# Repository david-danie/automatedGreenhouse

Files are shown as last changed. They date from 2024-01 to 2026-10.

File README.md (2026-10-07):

# SmartPlant — Controlador de Cultivo IoT

<div align="justify">

SmartPlant es un sistema embebido que controla iluminación por espectro, riego y ventilación de un cultivo indoor, y se configura desde el celular mediante un portal Wi-Fi servido por el propio microcontrolador — sin app, sin nube obligatoria, sin frameworks de terceros. La principal motivación de este proyecto es generar **independencia alimentaria** respecto a las especies que se adapten a estas tecnologías, contemplando principalmente hortalizas.

</div>

<br>
<div align="center">
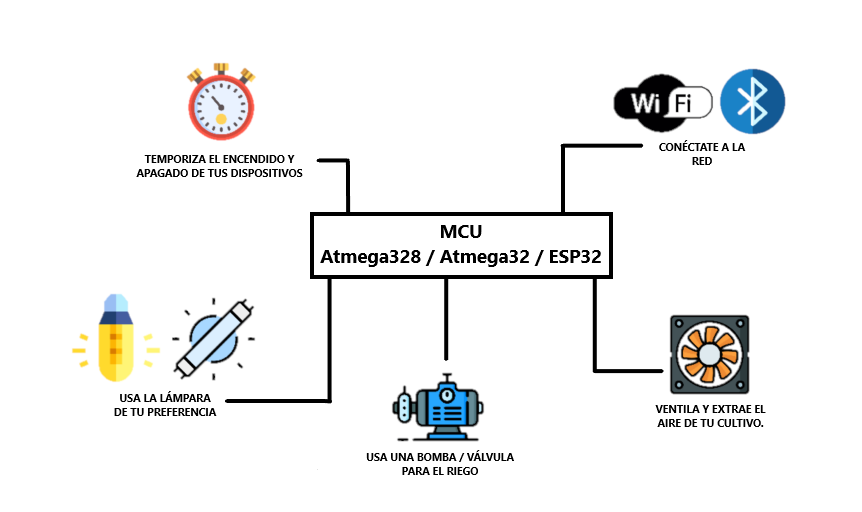
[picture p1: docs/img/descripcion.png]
Diagrama general del sistema
  
</div>
<br>

<div align="justify">

SmartPlant está construido sobre un **ESP32-C3** (RISC-V, 1 núcleo @160 MHz) con portal captivo, frontend embebido y una arquitectura pensada para escalar hacia un backend con telemetría y OTA segura.

</div>

<br>

`C++` · `ESP32-C3` · `Arduino / ESP-IDF` · `Vanilla JS` · `HTML/CSS` · `mbedTLS (planned)` · `FastAPI + PostgreSQL (in progress)`

---

## CONTENIDO

* [QUÉ DEMUESTRA ESTE PROYECTO.](#qué-demuestra-este-proyecto)
* [DECISIONES DE INGENIERÍA.](#decisiones-de-ingeniería)
* [CARACTERÍSTICAS.](#características)
* [ARQUITECTURA.](#arquitectura)
* [EL PORTAL.](#el-portal)
* [DISPOSITIVOS A CONTROLAR.](#dispositivos-a-controlar)
  - [Lámparas de cultivo.](#lámparas-de-cultivo)
  - [Bomba para irrigación.](#bomba-para-irrigación)
  - [Ventilación/Extracción.](#ventilaciónextracción)
* [TARJETA DE CONTROL.](#tarjeta-de-control)
* [STACK TECNOLÓGICO.](#stack-tecnológico)
* [ESTRUCTURA DEL REPOSITORIO.](#estructura-del-repositorio)
* [COMPILAR Y FLASHEAR.](#compilar-y-flashear)
* [ROADMAP.](#roadmap)
* [DOCUMENTACIÓN.](#documentación)

---

## QUÉ DEMUESTRA ESTE PROYECTO

<div align="justify">

Un sistema **embebido de extremo a extremo** construido bajo restricciones reales de hardware (1 núcleo RISC-V @160 MHz, RAM y flash limitadas):

- **Firmware en C++** para ESP32-C3: PWM multicanal, relés, RTC por I²C, persistencia en NVS, servidor HTTP y DNS captivo.
- **Frontend embebido**: una SPA completa (máquina de estados) en un solo HTML con vanilla JS, servida desde el flash del dispositivo — sin build, sin dependencias.
- **Diseño con trade-offs documentados**: cada decisión no trivial (scheduling, sesión, conectividad, validación) está razonada en el código y en la documentación técnica.
- **Mentalidad de producto**: UX cuidada (transiciones, estados de error, accesibilidad), seguridad por capas y un roadmap de backend/OTA pensado para el hardware.

</div>

---

## DECISIONES DE INGENIERÍA

<div align="justify">

La parte interesante de un proyecto embebido no es solo *qué* hace, sino *cómo* resuelve los problemas difíciles que impone el hardware. A continuación se documentan las decisiones más relevantes:

</div>

| Reto | Solución |
|---|---|
| **Que el riego sobreviva cortes de luz** | Scheduling **stateless**: el encendido se recalcula desde un contador continuo de horas derivado del RTC (`epochHours % intervalo`). El mismo modelo cubre riego sub-diario y espaciado de varios días, sin depender de un contador que se perdería al apagarse. |
| **Edad del cultivo correcta tras estar apagado** | `día`/`semana` se **derivan del calendario real** (ancla `cropStart` en NVS), no de un contador — el cultivo "sigue envejeciendo" aunque el equipo estuviera off, sin desgastar flash cada noche. |
| **Conectar a Wi-Fi sin congelar el portal** | Conexión STA **no bloqueante** + **polling** desde el front: el `POST` solo arranca el intento y responde al instante; el cliente confirma vía `/getparams`. Evita bloquear `handleClient()` varios segundos. |
| **No guardar una contraseña Wi-Fi que no sirve** | **Persistencia diferida**: las credenciales se escriben en NVS *solo* cuando la conexión llega a `WL_CONNECTED` — nada de bucles de reintento tras reiniciar con credenciales inválidas. |
| **Autenticación sin reenviar credenciales** | **Token de sesión** de 128 bits (`esp_random()`), TTL fijo en RAM (muere con el reboot, expiración por `millis()` a prueba de wrap-around). El AP va cifrado con WPA2-PSK. |
| **Validación idéntica en navegador y dispositivo** | Reglas replicadas bit a bit front↔firmware, contando por **carácter UTF-8** (no bytes), para que acentos y ñ no descuadren los límites entre JS y C++. |
| **Servir 50 KB de HTML sin agotar el heap** | `send_P` entrega el portal por trozos directo desde flash. Con `send()` y un `const char*` se creaba un `String` temporal del tamaño completo, y ese pico podía fallar en modo AP+STA dejando el formulario sin cargar. |
| **Menos flash y carga más rápida del portal** | El HTML legible (fuente de verdad) se regenera sin comentarios y **comprimido con gzip** al artefacto que sirve el ESP32: de ~93 KB a **~16 KB (−83 %)**. `handleRoot` lo entrega con `Content-Encoding: gzip` y el navegador lo descomprime solo. |

---

## CARACTERÍSTICAS

<div align="justify">

- **Portal captivo Wi-Fi** (AP "SmartPlant" con WPA2): se configura desde cualquier navegador, sin instalar nada.
- **Iluminación por espectro** (azul / rojo vía PWM, blanco ON/OFF), con fotoperiodo que puede cruzar medianoche.
- **Riego y ventilación** programables por intervalo (de cada hora a semanal).
- **RTC externo DS3231**: la hora se sincroniza desde el navegador del usuario.
- **Conectividad Wi-Fi del usuario** (modo AP+STA condicional) para habilitar nube/telemetría a futuro.
- **Sesión con token** + reset de fábrica protegido.
- **Aplicación de parámetros en vivo** (sin reiniciar el dispositivo).

</div>

---

## ARQUITECTURA

```
┌──────────────┐   Wi-Fi (WPA2)   ┌─────────────────────────────┐
│  📱 Cliente   │ ────────────────▶│   ESP32-C3  "SmartPlant"    │
│ (navegador)  │   HTTP / JSON    │ ┌─────────────────────────┐ │
└──────────────┘                  │ │ Portal captivo (AP)     │ │
                                  │ │ SPA en 1 HTML (vanilla) │ │
                                  │ └─────────────────────────┘ │
   red del usuario   ◀────────────│ ┌─────────────────────────┐ │
   (Internet, futuro)             │ │ STA  (AP+STA condicional)│ │
                                  │ └─────────────────────────┘ │
                                  │  PWM LEDs · Bomba · Fan ·   │
                                  │  RTC DS3231 · NVS · Token   │
                                  └─────────────────────────────┘
```

<div align="justify">

El frontend es una **máquina de estados** (`welcome · register · view · auth · edit · wifi`) contenida en un único archivo HTML; el firmware expone una API JSON y aplica la configuración al instante. Toda la comunicación entre el navegador y el microcontrolador ocurre dentro de la red local del AP — no se requiere internet para operar.

El detalle de cada decisión está en [`docs/ARCHITECTURE.md`](docs/ARCHITECTURE.md); el contrato completo de la API en [`docs/API.md`](docs/API.md).

</div>

---

## EL PORTAL

<div align="justify">

Al conectarse a la red **SmartPlant**, el sistema operativo detecta el portal captivo y abre el formulario automáticamente. Todo el frontend es un único archivo HTML con JavaScript vanilla servido desde el flash del microcontrolador: sin build, sin CDN, sin dependencias.

</div>

<br>
<table align="center">
  <tr>
    <th>Dashboard.</th>
    <th>Edición de parámetros.</th>
    <th>Configuración de red.</th>
  </tr>
  <tr>
    <td>Dashboard del portal</td>
    <td>Edición de parámetros</td>
    <td>Configuración de red Wi-Fi</td>
  </tr>
</table>
<br>

<div align="justify">

El dashboard muestra el estado del cultivo en modo lectura; para editar hay que autenticarse, lo que emite un token de sesión válido 30 minutos. La vista de red escanea las señales disponibles y permite conectar el dispositivo a la Wi-Fi del usuario sin perder el acceso al portal.

</div>

---

## DISPOSITIVOS A CONTROLAR

<div align="justify">

Los invernaderos ofrecen muchas ventajas sobre los métodos de agricultura tradicionales. El cultivo de algunas plantas y hortalizas puede adaptarse a espacios dedicados en la ciudad. La tecnología usada en la agricultura protegida también se puede adaptar a estos lugares y puede contemplar la automatización de tareas como el riego, la ventilación y/o extracción de aire, control de fotoperiodo y también la medición de parámetros como temperatura, humedad, pH, etc.

</div>

#### LÁMPARAS DE CULTIVO.

<div align="justify">

El sol como fuente de energía es muy potente e influye directamente en el desarrollo de vida. Dentro del espectro de radiación solar encontramos la radiación fotosintéticamente activa (PAR), donde los tonos azules y rojos son los más influyentes en el desarrollo de las plantas. La tecnología LED en la actualidad ofrece alternativas para suministro de luz en los cultivos. En la implementación actual se dispone de **2 canales PWM** (azul, rojo) que permiten controlar la intensidad de cada espectro de forma granular (0–100 %), más un **canal digital ON/OFF** para el blanco, con un fotoperiodo configurable que admite cruce de medianoche.

</div>

<br>
<table align="center">
  <tr>
    <th>LEDs rojos y azules.</th>
    <th>LEDs blancos.</th>
    <th>Otras lámparas.</th>
  </tr>
</table>
<div align="center">
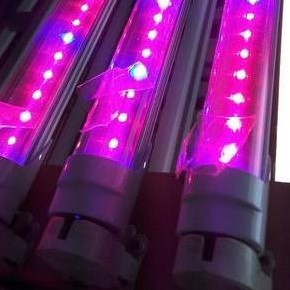
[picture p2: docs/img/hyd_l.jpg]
LEDs rojos y azules
  &emsp;&emsp;&emsp;&emsp;
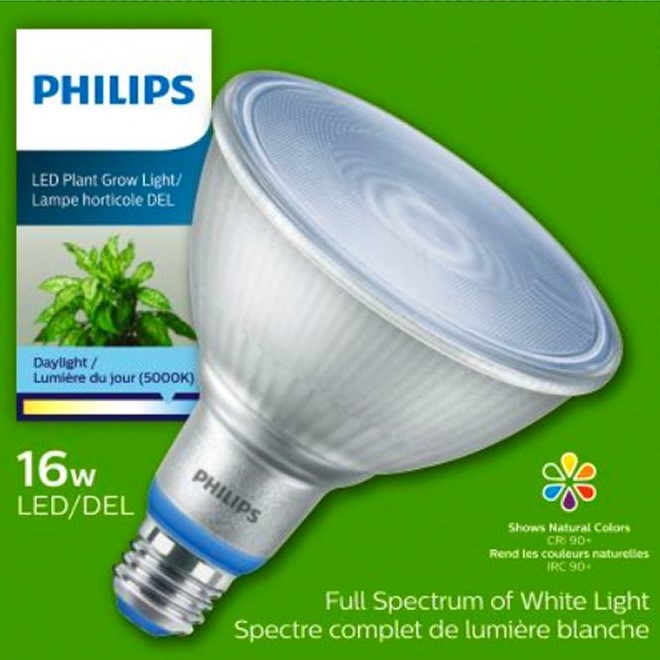
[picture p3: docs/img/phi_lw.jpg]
LEDs blancos
  &emsp;&emsp;&emsp;&emsp;
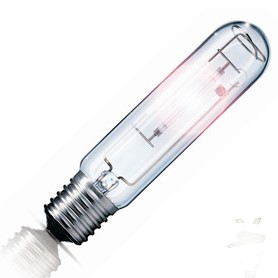
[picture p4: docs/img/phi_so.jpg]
Otras lámparas
  
</div>
<br>

#### BOMBA PARA IRRIGACIÓN.

<div align="justify">

Hay diferentes métodos de riego en la agricultura: riego por aspersión, por goteo, por gravedad, película de nutrientes, entre otros. Se hace la generalización de controlar el encendido/apagado de una bomba de agua o una electroválvula para realizar esta tarea. El sistema actual implementa un **scheduling stateless** que recalcula los ciclos de riego directamente desde el RTC, de modo que el riego se ejecuta correctamente incluso después de un corte de energía sin necesidad de persistir contadores.

</div>

<br>
<table align="center">
  <tr>
    <th>&emsp;Goteo.&emsp;</th>
    <th>&emsp;Gravedad.&emsp;</th>
    <th>&emsp;Método NFT.&emsp;</th>
    <th>&emsp;Válvula E.&emsp;</th>
  </tr>
</table>
<div align="center">
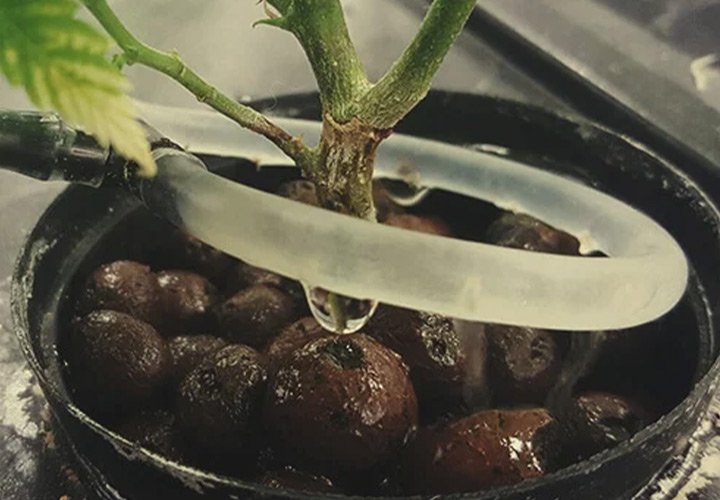
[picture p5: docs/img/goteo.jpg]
Riego por goteo
  &emsp;&emsp;&emsp;&emsp;
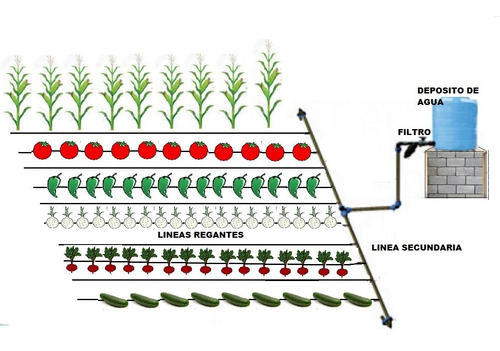
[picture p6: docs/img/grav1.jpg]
Riego por gravedad
  &emsp;&emsp;&emsp;&emsp;
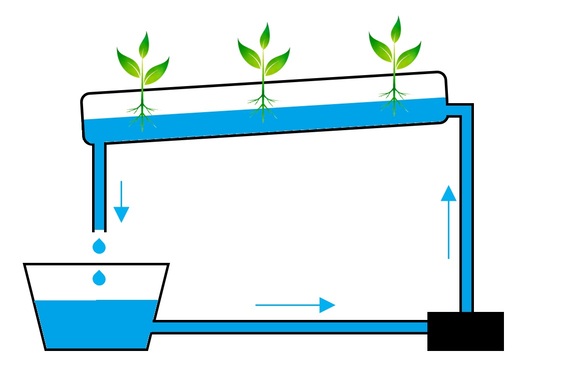
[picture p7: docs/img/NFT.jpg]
Método NFT
  &emsp;&emsp;&emsp;&emsp;
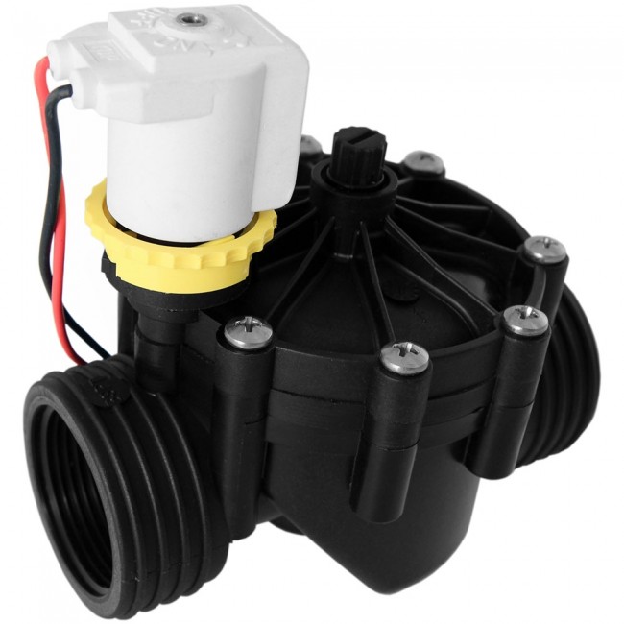
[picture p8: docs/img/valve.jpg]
Electroválvula
  
</div>
<br>

#### VENTILACIÓN/EXTRACCIÓN.

<div align="justify">

La calidad del aire de los espacios de cultivo influye en la temperatura y por lo tanto en el desarrollo de las plantas. Si es necesario forzar la circulación de aire limpio en los invernaderos y eliminar el aire viciado, se incluyen equipos de extracción y ventilación. El sistema controla un relé (lógica directa) para activar el ventilador/extractor en intervalos configurables desde el portal.

</div>

---

## TARJETA DE CONTROL

<div align="justify">

El controlador es un **ESP32-C3** (RISC-V, 1 núcleo @160 MHz) que integra Wi-Fi nativo y sirve el portal web completo directamente desde el microcontrolador.

</div>

| Componente | GPIO | Notas |
|---|---|---|
| LED blanco | 0 | Salida digital (lógica directa) |
| LED azul | 1 | PWM canal 1 |
| LED rojo | 2 | PWM canal 2 |
| Buzzer | 3 | Señalización sonora |
| Ventilador | 7 | Relé (lógica directa) |
| Bomba de agua | 10 | Relé (lógica directa) |
| RTC DS3231 | I²C `0x68` | Reloj externo para scheduling |

<div align="justify">

PWM configurado a 1 kHz con resolución de 8 bits (0–255). Los valores de espectro se envían desde el portal como porcentaje (0–100 %) y se escalan internamente en el firmware.

El detalle completo —esquemáticos, salidas SSR, RTC e instalación eléctrica— está en **[`docs/HARDWARE.md`](docs/HARDWARE.md)**.

</div>

---

## STACK TECNOLÓGICO

<div align="justify">

- **MCU:** ESP32-C3 (RISC-V, 1 núcleo @160 MHz)
- **Firmware:** C++ (Arduino-ESP32 / ESP-IDF) — `WiFi`, `WebServer`, `DNSServer`, `Wire`, `Preferences`, `ArduinoJson` (v6)
- **Frontend:** HTML + CSS + JavaScript vanilla (sin frameworks, sin build)
- **Persistencia local:** NVS (Preferences)
- **Backend (diseño cerrado, corriendo con auth y provisión):** Python (FastAPI), PostgreSQL + TimescaleDB, MQTT, almacenamiento S3-compatible. La infraestructura levanta en Docker, Alembic crea todo el esquema, el registro/login de usuarios funciona y los dispositivos ya se vinculan a una cuenta con su propio token; lo que sigue es recibir configuración y telemetría.
- **Planeado:** TLS (mbedTLS) y OTA firmada

</div>

---

## ESTRUCTURA DEL REPOSITORIO

```
.
├── ESP32_controller/          # Firmware (sketch de Arduino)
│   ├── ESP32_controller.ino   # AP Wi-Fi, DNS captivo, rutas HTTP y handlers
│   ├── Plant.h / .cpp         # Lógica del cultivo: validación, PWM/relés, RTC, sesión, Wi-Fi
│   ├── Constants.h            # Pines, PWM, límites de validación, enums de estado/error
│   ├── utils.h / .cpp         # Helpers: validación de strings/UTF-8, BCD, fecha
│   ├── sensible.h             # Secretos del AP (no versionado)
│   └── mainForm.h             # Artefacto generado: el HTML que sirve el ESP32
├── HTML/
│   ├── mainForm.html          # Pista ESTABLE (producción): fuente del portal
│   ├── mainForm.preview.html  # Preview de la estable (generado, con mock)
│   └── portal-dev/             # Pista DESARROLLO (pruebas): mainForm.html (fuente),
│                              #   mainForm.preview.html (generado) y paletas-guardadas.css
├── scripts/                   # Generadores: gen_mainform.py (--dev), gen_preview.py, gen_preview_dev.py
├── ESP32_Board/               # Diseño de la tarjeta (KiCad)
├── pythonServer/              # Backend: FastAPI + Alembic + Docker (auth funcional)
├── docs/                      # Documentación técnica
│   ├── README.md              # Índice de la documentación
│   ├── ARCHITECTURE.md        # Diseño del firmware y del portal
│   ├── API.md                 # Referencia de la API HTTP
│   ├── HARDWARE.md            # Pines, periféricos, instalación eléctrica
│   ├── BACKEND.md             # Diseño del backend
│   └── img/                   # Imágenes y diagramas
├── README.md
└── README.en.md
```

<div align="justify">

**Convención del portal — dos pistas.** El formulario se mantiene en **dos pistas** permanentes, cada una con su fuente legible y comentada:

- **Estable** (producción): `HTML/mainForm.html`
- **Desarrollo** (pruebas / features nuevas, p. ej. temperatura/humedad): `HTML/portal-dev/mainForm.html`

Se edita la fuente de cada pista y de ahí se regeneran sus artefactos, **nunca al revés**:

```bash
# Previews para revisar en el navegador sin dispositivo (cada uno inyecta su propio
# mock de fetch/XHR que simula el firmware):
python3 scripts/gen_preview.py     # -> HTML/mainForm.preview.html            (estable)
python3 scripts/gen_preview_dev.py  # -> HTML/portal-dev/mainForm.preview.html  (desarrollo)

# Promover UNA pista al artefacto embebido que sirve el ESP32 (un solo .h; se elige cuál):
python3 scripts/gen_mainform.py        # -> ESP32_controller/mainForm.h  desde la ESTABLE
python3 scripts/gen_mainform.py --dev  # -> ESP32_controller/mainForm.h  desde DESARROLLO
```

El firmware sirve **un solo** `mainForm.h`, así que promover = elegir qué pista lo
sobrescribe. Cada preview tiene su propio mock (pueden divergir a propósito: la pista de
desarrollo simula lo que va probando).

</div>

---

## COMPILAR Y FLASHEAR

```bash
# Requisitos: Arduino IDE / arduino-cli con el core ESP32 y ArduinoJson (v6).
# 1. Crear sensible.h con las credenciales del AP (ver plantilla en el código).
# 2. Compilar y flashear el sketch ESP32_controller/ a la placa ESP32-C3.
# 3. Conectarse a la red Wi-Fi "SmartPlant" → el portal captivo abre el formulario.
```

<div align="justify">

No hay test runner automatizado: la validación se hace en hardware. El JS del portal se verifica con `node --check` tras regenerar `mainForm.h` desde el HTML fuente.

</div>

---

## ROADMAP

- [x] Portal captivo + dashboard + edición de parámetros en vivo
- [x] Sesión con token (sin reenviar credenciales)
- [x] Conectividad Wi-Fi del usuario (AP+STA, escaneo asíncrono, conexión + polling)
- [x] Interruptor general del cultivo (`enable`) que realmente inhibe todos los actuadores
- [x] Modo seguro del RTC: sin hora fiable (bit OSF del DS3231) no se acciona nada
- [x] **Seguridad del portal** — los tres huecos conocidos, resueltos
      ([ver detalle](docs/ARCHITECTURE.md#huecos-de-seguridad-identificados-y-su-resolución)):
  - [x] Contraseña de usuario **hasheada** con PBKDF2-HMAC-SHA256 + salt de 16 B (queda calibrar las iteraciones en la placa)
  - [x] Reset de fábrica **restringido a la interfaz del AP**, y operación rutinaria separada en `POST /newcrop` (autenticada, conserva cuenta y Wi-Fi)
  - [x] **Límite de intentos** de login: espera creciente de 5 s a 5 min, contador en RAM
- [x] Servir el portal **gzip** (`Content-Encoding: gzip`): `gen_mainform.py` comprime el HTML y lo embebe como arreglo de bytes (`mainForm_gz`); `handleRoot` lo sirve con el encabezado. Reduce el portal de ~93 KB a ~16 KB (−83 %). Falta probarlo en hardware.
- [ ] **Portal V2** (rediseño hub-and-spoke, en desarrollo en `HTML/portal-dev/`): estructura, JS y **diseño visual completo** con **paletas intercambiables** (claras: tierra/invernadero/slate; oscura: verde-oscuro; ver `paletas-guardadas.css` y el comparador). Falta el repaso visual fino y **homologarlo** (promover con `gen_mainform.py --dev` + generar su `mainForm.h`) como versión oficial ([ver estado](docs/ARCHITECTURE.md))
- [x] **OTA local** (subir el `.bin` desde el teléfono por el AP, sin internet): endpoint `POST /otaupdate` en el firmware (librería `Update`), `partitions.csv` con dos slots OTA y **cliente en ambos portales** (V1 y V2, vistas `ota`/`flashing` con barra de progreso). Falta probar el flujo completo en hardware real ([ver requisitos](docs/ARCHITECTURE.md#requisito-crítico-tabla-de-particiones-con-dos-slots-ota))
- [ ] **Backend** (FastAPI + Postgres/Timescale): cuentas, telemetría y consulta entre dispositivos. Ya está en pie la base — la infraestructura corre en Docker (Postgres/Timescale, MinIO y Mosquitto), Alembic crea el esquema completo (5 tablas + hypertable), el registro/login/refresh funciona con JWT y los dispositivos se vinculan a una cuenta recibiendo su propio token revocable. En curso: recibir configuración y telemetría por REST (escrito, pendiente de probar). Falta exponer las lecturas para la app, servir OTA y la ingesta por MQTT ([ver estado](pythonServer/README.md))
- [ ] **OTA segura** sobre TLS (CA pinning + firmware firmado)
- [ ] Medición de temperatura y humedad (DS18B20 contemplado en el diseño original)
- [ ] **Migración del firmware a ESP-IDF**: profesionalizar el firmware (tooling, control de RAM/flash, OTA de doble slot y TLS) migrando de Arduino-ESP32 a ESP-IDF por fases entregables. El plan completo —motivación, clasificación del código, mapeo de APIs Arduino → ESP-IDF y criterios de verificación por fase— está en [`docs/ROADMAP.md`](docs/ROADMAP.md)

---

## DOCUMENTACIÓN

<div align="justify">

Toda la documentación técnica vive en **[`docs/`](docs/README.md)**:

- **[docs/ARCHITECTURE.md](docs/ARCHITECTURE.md)** — diseño técnico a fondo: decisiones, trade-offs, caveats, máquina de estados del portal, modelo de BD y estrategia TLS para el C3.
- **[docs/API.md](docs/API.md)** — referencia completa de la API HTTP: rutas, payloads, validaciones, catálogo de errores y ejemplos con `curl`.
- **[docs/HARDWARE.md](docs/HARDWARE.md)** — mapa de pines, PWM, RTC, SSR, conectividad e instalación eléctrica.
- **[docs/BACKEND.md](docs/BACKEND.md)** — diseño del backend (FastAPI + Postgres/Timescale + MQTT + S3): decisiones, modelo de datos y contratos de API. Es la referencia para implementarlo.
- **[docs/ROADMAP.md](docs/ROADMAP.md)** — plan de migración del firmware a ESP-IDF por fases: motivación, clasificación del código actual, mapeo de APIs Arduino → ESP-IDF y criterios de verificación.
- **[pythonServer/README.md](pythonServer/README.md)** — cómo levantar el backend local (FastAPI + Postgres/Timescale, MinIO, Mosquitto).

</div>

---

<div align="center">

**SmartPlant v1.0** · Firmware embebido + portal captivo para cultivo IoT

</div>

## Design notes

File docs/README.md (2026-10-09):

# Documentación de SmartPlant

Índice de la documentación técnica. Para la presentación general del proyecto, empieza por el [README de la raíz](../README.md).

---

## Por documento

| Documento | Contenido | Cuándo consultarlo |
|---|---|---|
| [**ARCHITECTURE.md**](ARCHITECTURE.md) | Diseño del firmware y del frontend a fondo: decisiones, trade-offs, caveats, máquina de estados del portal, modelo de BD y estrategia TLS para el C3 | Para entender *por qué* el código está escrito así |
| [**API.md**](API.md) | Referencia completa de la API HTTP **del dispositivo**: rutas, payloads, validaciones, catálogo de errores y ejemplos con `curl` | Para integrar algo contra el dispositivo |
| [**API-backend.md**](API-backend.md) | Referencia de la API HTTP **del backend** (nube): auth, provisión, config/telemetría del dispositivo y lecturas de la app; qué está implementado y qué no | Para integrar la app o el dispositivo contra la nube |
| [**HARDWARE.md**](HARDWARE.md) | Mapa de pines, PWM, RTC, etapa de potencia (control ↔ potencia), conectividad e instalación eléctrica | Para montar o modificar el hardware |
| [**BACKEND.md**](BACKEND.md) | Diseño del backend y **referencia autoritativa** para implementarlo: stack, modelo de datos, contratos de API, despliegue | Para retomar el desarrollo del backend |
| [**ROADMAP.md**](ROADMAP.md) | Plan de migración del firmware de Arduino-ESP32 a ESP-IDF, por fases entregables: motivación, clasificación del código, mapeo de APIs y criterios de verificación | Para planear o retomar la migración a ESP-IDF |

## Por tarea

**Quiero flashear el dispositivo y usarlo** → [README § Compilar y flashear](../README.md#compilar-y-flashear), luego [HARDWARE.md](HARDWARE.md) para el conexionado.

**Quiero modificar el portal web** → [ARCHITECTURE.md](ARCHITECTURE.md) explica la máquina de estados y la convención de regenerar `mainForm.h` desde `HTML/mainForm.html`.

**Quiero agregar o cambiar una ruta HTTP** → [API.md](API.md) es el contrato; mantenlo sincronizado con `ESP32_controller.ino` y `Plant.cpp`.

**Quiero integrar la app o el dispositivo contra la nube** → [API-backend.md](API-backend.md) es la referencia de la API del backend (lo implementado y lo pendiente); mantenla sincronizada con `pythonServer/app/routers/`.

**Quiero trabajar en el backend** → [BACKEND.md](BACKEND.md) es el diseño a implementar (referencia única); [pythonServer/README.md](../pythonServer/README.md) explica cómo levantar la infraestructura local.

**Quiero cambiar un pin o un periférico** → [HARDWARE.md](HARDWARE.md), y `ESP32_controller/Constants.h` es la fuente de verdad.

---

## Convenciones

**`Constants.h` es la fuente de verdad del hardware y de los límites de validación.** Pines, canales PWM, longitudes de campo y `validFrequencies` se definen ahí. La documentación los refleja; si divergen, el código gana.

**El portal tiene dos archivos y una dirección.** `HTML/mainForm.html` es la fuente legible y comentada; `ESP32_controller/mainForm.h` es el artefacto que sirve el dispositivo, generado a partir del anterior quitando comentarios y envolviéndolo en un raw string de C. **Se edita el `.html` y se regenera el `.h`**, nunca al revés.

**Las validaciones están duplicadas a propósito.** El navegador y el firmware aplican las mismas reglas (charset, longitudes, repetidos) contando por carácter UTF-8. Si cambias una, cambia la otra: `HTML/mainForm.html` y `Plant.cpp` / `utils.cpp`.

**Las imágenes viven en [`img/`](img).** Referéncialas con rutas relativas (`./img/archivo.png`) para que funcionen tanto en GitHub como en visores locales de Markdown.

---

## Estado del proyecto

| Área | Estado |
|---|---|
| Firmware ESP32-C3 | Funcional: portal captivo, scheduling, RTC con modo seguro, sesión, Wi-Fi AP+STA con escaneo asíncrono |
| Portal web embebido | Funcional: dashboard, edición en vivo, configuración de red |
| Hardware | Prototipo; PCB de la versión ESP32 en [`ESP32_Board/`](../ESP32_Board) (KiCad) |
| Seguridad del portal | Los tres huecos resueltos: contraseña con PBKDF2, reset restringido al AP y límite de intentos de login — [ARCHITECTURE.md](ARCHITECTURE.md#huecos-de-seguridad-identificados-y-su-resolución) |
| OTA local | Implementada: endpoint `POST /otaupdate` (firmware, librería `Update`) + `partitions.csv` de doble slot + cliente en **ambos portales** (V1 y V2). Falta probar el flujo completo en hardware — [ARCHITECTURE.md](ARCHITECTURE.md#otaupdate) |
| Portal gzip | Implementado: `gen_mainform.py` comprime el HTML (~93 KB → ~16 KB) y `handleRoot` lo sirve con `Content-Encoding: gzip`. Falta probar en hardware — [ARCHITECTURE.md](ARCHITECTURE.md#servir-el-html-comprimido-gzip) |
| Backend | Auth + provisión + config/telemetría + lecturas app-facing **implementados y verificados** end-to-end; faltan OTA/admin y MQTT — [BACKEND.md](BACKEND.md) / [API-backend.md](API-backend.md) |
| OTA segura | No iniciada; estrategia analizada en [ARCHITECTURE.md](ARCHITECTURE.md) |

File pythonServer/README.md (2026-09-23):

# SmartPlant — Backend

Servicio de nube para SmartPlant: cuentas de usuario, vinculación de dispositivos, telemetría y distribución de firmware OTA.

> **Estado: auth, provisión, config, telemetría y lecturas para la app operativas y verificadas.**
>
> El backend corre en Docker junto a la infraestructura. La migración de Alembic crea el
> esquema completo (5 tablas + hypertable), los endpoints de autenticación están operativos
> y `POST /devices/provision` ya vincula dispositivos y emite su token (todo verificado
> end-to-end).
>
> El ciclo dispositivo↔nube por REST está cerrado y verificado: `POST /devices/{id}/config`
> (histórico) y `POST /devices/{id}/telemetry` (`ts` server-side, refresca presencia). Y las
> **lecturas para la app** (§4.2) también: `GET /me/devices`, `GET /devices/{id}/state`
> (con edad de cultivo derivada) y `GET /devices/{id}/telemetry` (histórico agregado con
> `time_bucket`), todas con **aislamiento por cuenta** (404, no 403, si el device es de otra).
>
> **El diseño completo a seguir implementando está en [`../docs/BACKEND.md`](../docs/BACKEND.md).**

---

## Qué hay aquí

```
pythonServer/
├── Dockerfile                # Imagen del backend (Python 3.11 slim + uvicorn)
├── docker-compose.yml        # Stack completo: DB + MinIO + Mosquitto + backend
├── alembic.ini               # Configuración de Alembic
├── alembic/                  # Migraciones
│   ├── env.py                # Entorno async para migraciones
│   └── versions/
│       └── 001_initial_schema.py  # Esquema inicial (extensión + tablas + hypertable)
├── app/                      # Código de la API
│   ├── main.py               # FastAPI app + health endpoint
│   ├── settings.py           # Config por variables de entorno (12-factor)
│   ├── database.py           # Conexión async SQLAlchemy
│   ├── models.py             # Modelos ORM (users, devices, configs, telemetry, firmware)
│   ├── security.py           # Hashing bcrypt + generación de tokens (compartido)
│   ├── deps.py               # Dependencias de auth (Bearer → dispositivo; JWT → usuario)
│   └── routers/
│       ├── auth.py           # POST /auth/register, /auth/login, /auth/refresh
│       ├── devices.py        # POST /devices/provision, /{id}/config, /{id}/telemetry
│       └── me.py             # GET /me/devices, /devices/{id}/state, /devices/{id}/telemetry
├── db/schema.sql             # DDL de referencia (la fuente real es Alembic)
├── mosquitto/config/         # Configuración del broker
├── requirements.txt          # Dependencias con versiones clave pinneadas
├── .env.example              # Plantilla de variables de entorno
└── README.md
```

---

## Levantar el stack

```bash
cd pythonServer
cp .env.example .env          # Ajusta secretos para tu entorno
docker compose up -d --build  # Construye el backend y levanta todo
docker compose exec backend alembic upgrade head  # Crea el esquema
```

Deja corriendo cuatro servicios:

| Servicio | Puerto | Qué es |
|---|---|---|
| `backend` | 8000 | API FastAPI (SmartPlant) |
| `db` | 5432 | Postgres 15 + TimescaleDB 2.14.2 |
| `minio` | 9000 · 9001 | Object storage S3 (API · consola web) |
| `mosquitto` | 1883 | Broker MQTT |

Consola de MinIO en `http://localhost:9001` (usuario/contraseña por defecto: `admin` / `admin123456`).

Documentación OpenAPI automática en `http://localhost:8000/docs`.

### Endpoints disponibles

| Método | Ruta | Descripción |
|---|---|---|
| GET | `/health` | Health check |
| POST | `/auth/register` | Crear cuenta (devuelve JWT) |
| POST | `/auth/login` | Autenticar (devuelve JWT) |
| POST | `/auth/refresh` | Renovar access token |
| POST | `/devices/provision` | Vincular dispositivo a una cuenta y emitir su token |
| POST | `/devices/{id}/config` | Registrar config del cultivo (Bearer) |
| POST | `/devices/{id}/telemetry` | Registrar lectura de telemetría (Bearer) |
| GET | `/me/devices` | Listar dispositivos de la cuenta (JWT usuario) |
| GET | `/devices/{id}/state` | Última config + telemetría + edad del cultivo (JWT usuario) |
| GET | `/devices/{id}/telemetry` | Histórico agregado con `time_bucket` (JWT usuario) |

### El esquema lo administra Alembic

`schema.sql` es material de referencia. El dueño real del esquema es Alembic:

```bash
docker compose exec backend alembic upgrade head   # Aplica migraciones pendientes
docker compose exec backend alembic downgrade -1   # Revierte la última
```

La migración `001_initial_schema.py` crea la extensión TimescaleDB, las 5 tablas del modelo
de datos, la hypertable sobre `device_telemetry` y los índices recomendados.

Detalle de por qué Alembic no autogenera la extensión ni `create_hypertable()` en el
[§8 de `BACKEND.md`](../docs/BACKEND.md).

---

## Siguiente paso

**OTA (entregable 7 del §8).** `POST /admin/firmware` (JWT admin) sube el binario a MinIO y
registra el release; `GET /firmware/latest?current=…` resuelve aplicabilidad y devuelve una
URL prefirmada. Después vienen MQTT (entregable 8) y TLS/Caddy (entregable 9).

Nota de entorno: por defecto el stack usa los puertos **5432** (Postgres) y **8000**
(backend). Si en tu máquina esos puertos están ocupados por otro proyecto, crea un
`docker-compose.override.yml` local que los remapee (p. ej. a **5433**/**8001**) con
`ports: !override` — sin esa directiva, Compose **concatena** las listas de puertos en vez
de reemplazarlas. Ese override es local de cada máquina y no forma parte del proyecto.

---

## Configuración

Todo por variables de entorno, sin nada hardcodeado (regla 1 del §7 de `BACKEND.md`).
Copia `.env.example` a `.env` y ajusta:

| Variable | Default (desarrollo) | Notas |
|---|---|---|
| `POSTGRES_USER` | `smartplant` | |
| `POSTGRES_PASSWORD` | `smartplant_secret` | |
| `POSTGRES_DB` | `smartplant_db` | |
| `DATABASE_URL` | `postgresql+asyncpg://...` | La usa el backend |
| `JWT_SECRET_KEY` | `change-me-in-production` | **Cambiar obligatorio** |
| `MINIO_ROOT_USER` | `admin` | |
| `MINIO_ROOT_PASSWORD` | `admin123456` | |
| `MQTT_HOST` | `mosquitto` | |

**Los defaults son solo para desarrollo local.** Para cualquier despliegue real, definirlos
en un `.env` fuera del control de versiones.

---

## Dos cosas pendientes de resolver

**Autenticación del broker.** Mosquitto está hoy con `allow_anonymous true`: cualquiera en
la red puede publicar y suscribirse. Sirve para desarrollo, no para nada expuesto. Las tres
salidas y la recomendación (arrancar la telemetría por REST) están en el
[caveat del §5 de `BACKEND.md`](../docs/BACKEND.md#caveat-mosquitto-no-autentica-contra-la-base-de-datos).

**Caddy + TLS.** El servicio `caddy` queda comentado en el compose hasta que se tenga un
dominio y un `Caddyfile` configurado.

---

## Cómo se autentican los dispositivos

Resumen; el detalle y los payloads están en el
[§4.0 de `BACKEND.md`](../docs/BACKEND.md).

El dispositivo se provisiona **una vez** enviando `{email, pass, mac}` sobre TLS a
`POST /devices/provision`. Es el único momento en que la contraseña del usuario viaja. El
backend valida la cuenta, vincula la fila en `devices` y emite un **token de dispositivo**;
de ahí en adelante el ESP32 usa `Authorization: Bearer <token>` y nunca almacena la
contraseña del usuario.

En la base se guarda solo `devices.token_hash`, así que una filtración no entrega
credenciales funcionales, y el token es revocable borrando o rotando esa fila.

Ojo con no confundirlo con el token de sesión del portal local del firmware, que es otra
cosa (RAM, 30 min, red local). La tabla comparativa está en el §4.0.

---

## Documentación relacionada

- **[`../docs/BACKEND.md`](../docs/BACKEND.md)** — el diseño a implementar. Referencia única.
- **[`../docs/API.md`](../docs/API.md)** — API HTTP del **dispositivo**, un contrato distinto
  al de este backend. Define las llaves que `device_configs` espeja.
- **[`../docs/ARCHITECTURE.md`](../docs/ARCHITECTURE.md)** — firmware; secciones de TLS en el
  ESP32-C3 y OTA sobre TLS.

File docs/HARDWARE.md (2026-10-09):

# Hardware

Tarjeta de control, mapa de pines, periféricos y instalación eléctrica.

El controlador es un **ESP32-C3** (RISC-V, 1 núcleo @160 MHz) con Wi-Fi nativo, que sirve el portal captivo desde su propia flash. El diseño eléctrico de potencia (SSR, contactores, gabinete) conmuta las cargas en CA.

---

## Contenido

- [Mapa de pines (ESP32-C3)](#mapa-de-pines-esp32-c3)
- [Control de potencia PWM](#control-de-potencia-pwm)
- [Temporización con RTC](#temporización-con-rtc)
- [Salidas digitales SSR](#salidas-digitales-ssr)
- [Etapa de potencia: acoplamiento control ↔ potencia](#etapa-de-potencia-acoplamiento-control--potencia)
- [Conectividad](#conectividad)
- [Instalación eléctrica](#instalación-eléctrica)
- [Medición de temperatura (DS18B20)](#medición-de-temperatura-ds18b20)

---

## Mapa de pines (ESP32-C3)

Definido en `ESP32_controller/Constants.h`.

| Componente | GPIO | Tipo | Notas |
|---|---|---|---|
| LED blanco | 0 | Digital | Lógica directa (`HIGH` = encendido) |
| LED azul | 1 | PWM canal 1 | 0–100 % desde el portal |
| LED rojo | 2 | PWM canal 2 | 0–100 % desde el portal |
| Buzzer | 3 | Digital | Señalización sonora no bloqueante (ver [vocabulario de pitidos](#vocabulario-de-pitidos)) |
| Ventilador / extractor | 7 | Relé | Lógica directa |
| Bomba de agua | 10 | Relé | Lógica directa |
| RTC DS3231 | I²C `0x68` | — | Bus `Wire`, para el scheduling |

**Polaridad centralizada:** el nivel que enciende vive en **un solo sitio**, las constantes `deviceOn`/`deviceOff` de `Constants.h`, hoy `HIGH`/`LOW` (lógica directa). Si se cambia a módulos de relé activos en bajo, basta intercambiar esas dos líneas y todo el firmware queda coherente.

**Estado inicial seguro:** `Plant::begin()` llama a `allDevicesOff()` antes de leer cualquier configuración, para que ningún actuador arranque energizado.

**La inicialización de hardware NO va en el constructor:** `Plant planta;` es un objeto global, así que su constructor corre durante la inicialización estática de C++, antes de que el framework de Arduino termine de preparar los periféricos. Configurar GPIO o LEDC ahí puede fallar en silencio o quedar sobrescrito, dejando un pin como entrada flotante en lugar de salida firme; el síntoma típico es un relé o LED con **brillo débil** que no conmuta bien. Por eso `pinMode`, `ledcAttachChannel` y el estado inicial se hacen en `begin()`, invocado desde `setup()`.

**Un solo canal digital para el blanco:** el blanco no tiene PWM asignado, así que solo admite ON/OFF. El portal envía `0` o `1` y el firmware evalúa `> 0`. Los espectros azul y rojo sí son regulables, que es donde la granularidad importa para el PAR.

---

## Control de potencia PWM

La modulación por ancho de pulso se usa aquí para regular la intensidad de cada canal LED de forma independiente, permitiendo adaptar el espectro a la etapa del cultivo — más azul en vegetativo, más rojo en floración.

| Parámetro | Valor |
|---|---|
| Frecuencia | 1 kHz |
| Resolución | 8 bits (duty 0–255) |
| Canales | 2 (azul, rojo) |

Los valores viajan del portal al firmware como **porcentaje 0–100** y se escalan internamente con `map(valor, 0, 100, 0, 255)`. Se eligió exponer porcentaje en la API para que el contrato no dependa de la resolución del PWM: si se sube a 10 bits, el frontend no cambia.

---

## Temporización con RTC

Para temporizar el encendido y apagado de los equipos se usa un **DS3231** por I²C (dirección `0x68`), compensado por temperatura y de baja deriva.

El firmware lee el RTC una vez por segundo desde `loop()` (único punto de I²C periódico, para no compartir el bus `Wire` con otras tareas) y con esa lectura decide qué salidas deben estar activas.

La hora **no** se configura con botones: se sincroniza desde el navegador del usuario en el `POST /newparams`, que incluye fecha y hora completas. El primer `/newparams` con fecha válida ancla `cropStart` en NVS, y a partir de ahí la edad del cultivo se **deriva** del calendario en vez de contarse, de modo que el cultivo sigue envejeciendo aunque el equipo estuviera apagado.

<table align="center">
  <tr>
    <th>Diagrama típico de conexión.</th>
    <th>Diagrama de conexión final.</th>
  </tr>
  <tr>
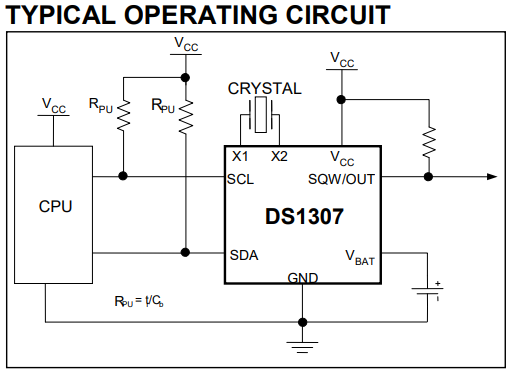
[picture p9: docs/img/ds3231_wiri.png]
Diagrama típico RTC
    <th></th>
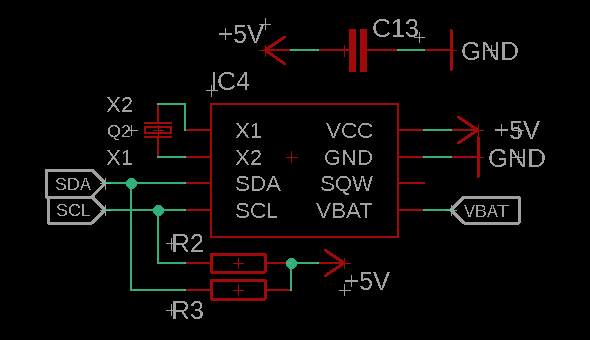
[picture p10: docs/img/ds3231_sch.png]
Diagrama esquemático RTC
    <th></th>
  </tr>
</table>

---

## Salidas digitales SSR

> **En revisión.** El SSR AQH2213 fue la elección de la **primera iteración** (por
> disponibilidad local en ese momento). Hoy es difícil de conseguir, así que la etapa de
> acoplamiento está **en rediseño** hacia MOSFET lógico + contactor con bobina de CD; ver
> [Etapa de potencia](#etapa-de-potencia-acoplamiento-control--potencia). Esta sección se
> conserva como referencia de la iteración previa.

Tres salidas digitales accionan los dispositivos (lámpara, bomba de agua y ventilador/extractor). Cada salida del MCU va a un SSR [AQH2213](https://b2b-api.panasonic.eu/file_stream/pids/fileversion/2787) con el circuito de protección que sugiere el fabricante para cargas inductivas, como la bobina de los contactores.

<table align="center">
  <tr>
    <th>Diagrama típico de conexión.</th>
    <th>Diagrama de conexión final.</th>
  </tr>
  <tr>
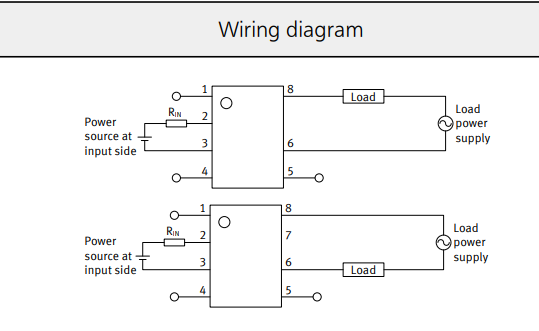
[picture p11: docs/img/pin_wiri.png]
Diagrama típico SSR
    <th></th>
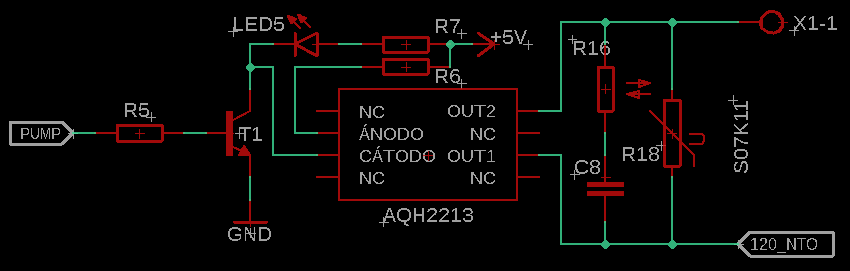
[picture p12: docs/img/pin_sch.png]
Diagrama esquemático SSR
    <th></th>
  </tr>
</table>

---

## Etapa de potencia: acoplamiento control ↔ potencia

Cómo se acopla la lógica del ESP32-C3 (3.3 V) con la potencia. Esta sección recoge las
decisiones de rediseño que sustituyen al SSR AQH2213 de la primera iteración.

### Decisiones tomadas

| Tema | Decisión | Por qué |
|---|---|---|
| **Fuente única** | **24 VCD** | A 120 W, 24 V tira ~5 A vs ~10 A a 12 V → mitad de corriente, ¼ de pérdidas (I²R), pistas y conectores más chicos, menos calor. A >60 W las fuentes de 24 V son tan comunes como las de 12 V. Una sola fuente alimenta LEDs, bobinas de contactor y (vía buck) el MCU. |
| **Dimensionado LED** | 60–120 W para 1–2 m², relación **1:5 azul:rojo con azul predominante** | Azul ≈ 100 W (~4.2 A @ 24 V, canal fuerte); rojo ≈ 20 W (~0.85 A). El hardware se dimensiona al **peor caso: cada canal al 100 %**. |
| **Salidas digitales (vent/bomba/blanco)** | **Contactor con bobina de CD (24 V)** accionado por **MOSFET lógico + diodo flyback** | Con bobina CD y tierra común NO hace falta optoacoplador: el **contactor es la barrera de aislamiento** hacia la CA. Más simple y barato que SSR/triac u opto+transistor. |
| **PWM LED (azul, rojo)** | **MOSFET lógico N-channel directo** (sin opto) | A 1 kHz un optoacoplador común (PC817) deforma la señal. El MOSFET lógico conmuta directo desde 3.3 V. |
| **MCU 3.3 V** | **Buck 24→5 V (→3.3 V)**, no lineal | Un lineal 24→3.3 disiparía demasiado; se usa un convertidor conmutado (p. ej. MP1584). |

### Pendiente de definir

- **Tipo de arreglo LED:** *voltaje constante (24 V)* vs *driver de corriente constante*.
  Decide la topología del canal PWM (ver abajo). **Mientras no se defina, el MOSFET exacto
  del canal azul queda tentativo.**
- **Bobina del contactor:** confirmar que se consiguen contactores con **bobina 24 VCD** y su
  consumo (corriente de retención y pico de arranque / inrush).

### Componentes propuestos (todos comunes / JLCPCB Basic)

| Función | Componente | Notas |
|---|---|---|
| MOSFET canal PWM (azul/rojo) | **IRLZ44N** (TO-220) o **AOD4184** (DPAK, SMD) | Logic-level, margen de V y RDS(on) para el canal azul ~4.2 A @ 24 V. El AO3400A (30 V, ~5.7 A) se queda **justo** a 24 V y a 3.3 V de gate su RDS(on) sube: solo para cargas pequeñas. |
| MOSFET bobina de contactor | **AO3400A** (SOT-23) | La bobina tira poco (<0.2 A típico); aquí el AO3400A sobra. |
| Diodo flyback (bobina CD) | **SS14** (Schottky SMD) o **1N4007** | **Obligatorio** en antiparalelo con la bobina CD: absorbe el pico inductivo (V=−L·di/dt) al cortar. |
| Resistencia de gate | **100 Ω** | En serie GPIO→gate. |
| Pull-down de gate | **100 kΩ** | Gate→GND. Mantiene el actuador apagado durante el boot del C3 (sus GPIO quedan indefinidos antes de que corra el firmware). |
| Convertidor MCU | Buck **24 V → 5 V** (MP1584 o equiv.) | De ahí al regulador 3.3 V. |
| Fuente | **24 VCD, 150 W** (o 100 W si tope 60 W) | ~125 % de la carga máxima. |
| LED indicador de salida | **LED + 4.7 kΩ** | Uno por salida digital, en paralelo con la bobina del contactor (~5 mA @ 24 V). Indica salida realmente energizada. |
| LED indicador de sistema | **LED + 680 Ω** | "24 V presente" en la fuente y, opcional, "3.3 V OK" tras el buck (~2 mA @ 3.3–5 V). |
| Buzzer | **Activo magnético 5 V** (HYDZ 12 mm, DIP) | 2.4 kHz fijo, ~30 mA, 85 dB. Alimentado a 5 V, conmutado por MOSFET pequeño + flyback (ver esquemático). Control no bloqueante en firmware (`buzzerBeep`/`buzzerUpdate`). |

### Esquemático — canal PWM de LED (voltaje constante)

Aplica si las tiras/arreglos son de **voltaje constante a 24 V**. Un canal por color
(GPIO 1 = azul, GPIO 2 = rojo):

```
            +24 V
              │
          [ ARREGLO LED ]        (azul o rojo)
              │
              │  Drain
 GPIO ──[100Ω]──┤ IRLZ44N / AOD4184 (N-ch, logic-level)
   │          │  Source
 [100k]       │
   │         GND
  GND
```

- `GPIO` = pin PWM (1 kHz, 8 bits). `100Ω` protege el pin; `100k` a GND mantiene el MOSFET
  apagado en el arranque.
- Si el arreglo lleva **driver de corriente constante**, el PWM NO va a este MOSFET: va a la
  **entrada de dimming (PWM/0–10 V)** del driver. Topología distinta — a definir.
- **Sin LED indicador dedicado** en los canales PWM a propósito: el propio arreglo LED ya es el
  indicador visual, y un LED colgado del PWM parpadearía a 1 kHz (brillo según el duty),
  confuso como indicador de estado.

> **Nota de pines (strapping):** el PWM rojo está en **GPIO 2**, que en el ESP32-C3 es
> *strapping pin* de boot. Un pull-down de 100 kΩ (alta impedancia) no suele afectar el
> arranque, pero conviene verificarlo; si da problemas, mover ese canal a un GPIO no-strapping.

### Esquemático — salida digital (contactor con bobina CD)

Aplica a ventilador, bomba y lámpara blanca (GPIO 7, 10, 0). El contactor conmuta la **CA**
de la carga; su bobina es de **24 VCD**:

```
            +24 V
              │
         [ BOBINA CONTACTOR 24 VCD ]
              │        ▲
              ├────────┤ cátodo   SS14 / 1N4007   (flyback, antiparalelo)
              │        ▼ ánodo
              │
              ├──[4.7k]──▶|── (LED indicador: salida activa)
              │
              │  Drain
 GPIO ──[100Ω]──┤ AO3400A
   │          │  Source
 [100k]       │
   │         GND
  GND

   (contactos del contactor) ── conmutan la carga en CA (120/240 V)
```

- El **flyback** va en antiparalelo con la bobina (cátodo a +24 V, ánodo al drain): sin él, el
  pico inductivo al apagar destruye el MOSFET.
- El **LED indicador** (en serie con `4.7 kΩ`) va **en paralelo con la bobina**, así enciende
  solo cuando la bobina está realmente energizada: confirma el camino completo
  GPIO→MOSFET→bobina, no solo lo que pide el firmware. El LED+R **no sustituye al flyback**;
  son elementos distintos. A ~5 mA: `R = (24−2)/0.005 ≈ 4.7 kΩ`, 1/4 W sobra.
- El **aislamiento hacia la CA lo da el contactor** (sus contactos separan la red de la
  electrónica de control). Por eso no se usa optoacoplador en la bobina de bajo voltaje.
- Si se quisiera una barrera extra por ruido de motores/bomba, se puede dejar **huella
  opcional de opto** y poblarla solo si hace falta — pero el diseño base va **sin** opto.

### Esquemático — buzzer (GPIO 3)

Buzzer **activo** (oscilador integrado: suena con solo aplicarle DC, tono fijo 2.4 kHz).
Control ON/OFF, igual que una salida digital. GPIO 3 ya está reservado para esto.

```
            +5 V  (riel del buck)
              │
          [ BUZZER activo 5 V ]
              │
              ├──▶|── 1N4148   (flyback: es magnético = inductivo)
              │
              │  Drain
 GPIO 3 ─[100Ω]─┤ 2N7002 / AO3400A
   │          │  Source
 [100k]       │
   │         GND
  GND
```

- **No se conecta directo al GPIO**: a 5 V y ~30 mA, el pin del C3 (3.3 V) no debe manejarlo
  directo. El MOSFET conmuta los 5 V; el GPIO 3 solo controla el gate (resuelve a la vez la
  corriente y el desajuste 3.3 V/5 V).
- **Flyback 1N4148** en antiparalelo: el buzzer magnético es inductivo.
- `100 Ω` gate + `100 kΩ` pull-down → mismo patrón que el resto; buzzer callado en el boot.
- A 3.3 V sonaría más débil (su óptimo es 5 V), por eso se alimenta del riel de 5 V.
- **Firmware:** el control del buzzer está implementado como salida digital no bloqueante
  (`pinMode` en `begin()`, máquina de estados `buzzerBeep`/`buzzerUpdate`). Ver el vocabulario
  de pitidos abajo.

#### Vocabulario de pitidos

El sonido comunica **qué** pasó, no solo "algo pasó". Los patrones se eligieron para que un
error no se confunda con una confirmación. Implementado con la máquina no bloqueante
(`buzzerBeep`/`buzzerUpdate`), salvo los eventos que reinician el equipo o son caminos de
error, que suenan síncronos en su handler (ver `ESP32_controller.ino`). Conteos en
`Constants.h` (`buzzerBeeps*`).

| Evento | Patrón | Disparo | Bloqueante |
|---|---|---|---|
| **Sistema listo** (boot) | 1 corto | fin de `setup()` | No |
| **Arranque sin RTC fiable** | 4 cortos | fin de `setup()` si `!isRtcValid()` | No |
| **Parámetros aplicados** | 3 cortos (330/330) | `/newparams` → `STATUS_OK` | No |
| **Login fallido / bloqueado** | 2 cortos | `MISMATCH_CREDENTIALS` / `TOO_MANY_ATTEMPTS` | No |
| **OTA correcta** | 1 largo (~600 ms) | `/otaupdate` OK, antes del reinicio | Sí (reinicia) |
| **OTA fallida** | 2 cortos | error 401/403/500 de `/otaupdate` | Sí (breve) |
| **Reset de fábrica** | 1 largo (~600 ms) | `HARD_RESET`, antes del reinicio | Sí (reinicia) |

**Deliberadamente SIN sonido:** las conmutaciones rutinarias de riego/luz/ventilación (muy
frecuentes, serían molestas) y el polling de Wi-Fi. El inicio de OTA tampoco pita, para no
interferir con la escritura del primer bloque en flash. El buzzer se reserva para **eventos de
usuario y de seguridad**.

### Diagrama de bloques

```
                         Fuente 24 VCD  ──[680Ω]──▶|  LED "24 V"
          ┌──────────────────┼───────────────────────────┐
          │                  │                            │
      buck 24→5→3.3     arreglos LED (24 V)        bobinas contactor (24 VCD)
          │             azul / rojo                  vent · bomba · blanco
       ESP32-C3            ▲   ▲                         ▲   ▲   ▲
          │  PWM 1 kHz ────┘   │                         │   │   │  cada bobina:
          │  (GPIO 1,2)        │        GPIO 7,10,0 ──────┘   │   │  ∥ LED+4.7k (indicador)
          └── MOSFET lógico ───┴──── MOSFET lógico + flyback ─┴───┘
                                                   │
                                            contactos CA → cargas 120/240 V
```

Los canales PWM no llevan LED indicador dedicado (el arreglo LED ya es su indicador).

---

El ESP32-C3 aprovecha su Wi-Fi integrado en **modo AP+STA**:

- **AP** (`SmartPlant`, WPA2-PSK): sirve el portal captivo. Siempre arriba.
- **STA**: se conecta a la red del usuario, solo si hay credenciales guardadas. Habilita telemetría y OTA a futuro.

Hay una sola radio, así que AP y STA comparten canal. Dos detalles que costaron depuración y quedan documentados en el firmware:

1. El modo dual se fija **explícitamente** con `WiFi.mode(WIFI_AP_STA)` antes de crear el SoftAP, para que `WiFi.begin()` del STA no reconfigure el modo por debajo.
2. Hay que **desactivar el modem-sleep** con `WiFi.setSleep(false)`. Con el STA habilitado, el ESP32 duerme la radio según el ciclo del STA (`WIFI_PS_MIN_MODEM` por defecto), lo que deja al SoftAP sin responder y el portal no carga.

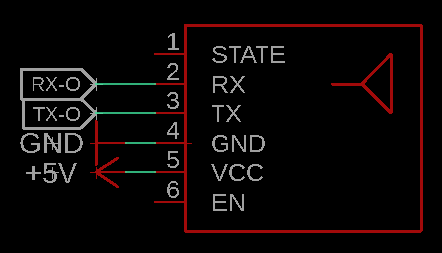
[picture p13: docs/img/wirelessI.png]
Interfaz inalámbrica


---

## Instalación eléctrica

Instalación propuesta para la conexión de los actuadores al gabinete de control. Las salidas del microcontrolador no accionan las cargas directamente: pasan por la [etapa de potencia](#etapa-de-potencia-acoplamiento-control--potencia) (MOSFET lógico) y de ahí a las bobinas de los contactores, que son los que conmutan la potencia en CA.

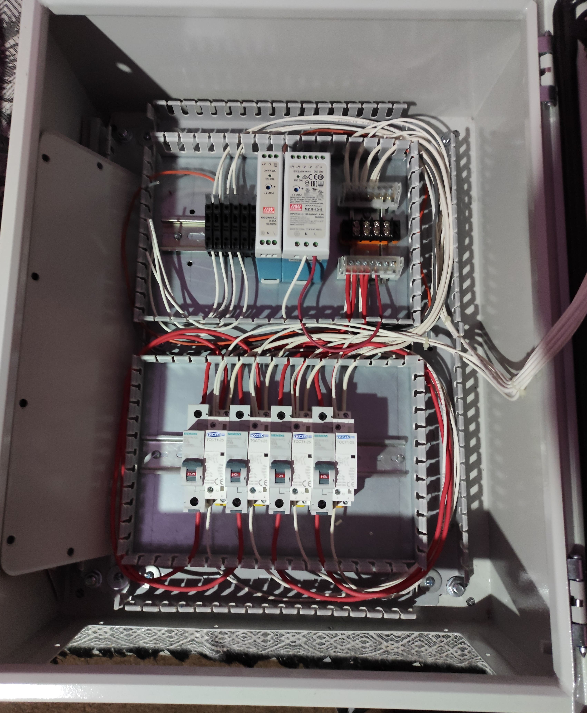
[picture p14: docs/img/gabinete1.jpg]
Gabinete eléctrico


La selección de contactores, los diagramas eléctricos y la conexión final se documentarán conforme avance la implementación en hardware.

---

## Medición de temperatura (DS18B20)

**Planeada, aún no implementada** en el firmware. Medir la temperatura del área de cultivo es una labor preventiva: conocer su comportamiento dentro de ciertos rangos ayuda a anticipar problemas. Queda para una futura actualización que además pueda ejecutar acciones correctivas.

Los archivos de diseño de la tarjeta están en [`ESP32_Board/`](../ESP32_Board) (KiCad).

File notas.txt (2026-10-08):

===========================================================================
 SmartPlant — Cómo levantar el sistema en otra computadora (Ubuntu)
===========================================================================

El proyecto tiene DOS mitades independientes:
  A) Backend  -> FastAPI + Postgres/Timescale + MinIO + Mosquitto (en Docker)
  B) Firmware -> ESP32-C3 (Arduino), sirve el portal web embebido

Levanta solo la que necesites. Nada de esto depende de macOS: en Ubuntu limpio
es más simple porque no chocan los puertos.

Dos archivos NO viajan con el proyecto (están en .gitignore) y hay que
recrearlos a mano en cada máquina:
  - pythonServer/.env                 (secretos del backend)
  - ESP32_controller/sensible.h       (credenciales del AP Wi-Fi del firmware)

---------------------------------------------------------------------------
 0. Traer el proyecto
---------------------------------------------------------------------------

  sudo apt update && sudo apt install -y git   # si usas git; si no, copia la carpeta
  # copia/clona la carpeta del proyecto y entra en ella
  cd automatedGreenhouse

---------------------------------------------------------------------------
 A. BACKEND (Docker)
---------------------------------------------------------------------------

1) Instalar Docker + Compose v2:

  sudo apt install -y docker.io docker-compose-v2
  sudo systemctl enable --now docker
  sudo usermod -aG docker $USER
  # cierra sesión y vuelve a entrar para que el grupo 'docker' tome efecto
  # (si no, antepon 'sudo' a los comandos docker)

2) Crear el .env (no viene en el repo):

  cd pythonServer
  cp .env.example .env
  # EDITA .env y cambia OBLIGATORIAMENTE:
  #   JWT_SECRET_KEY   -> cualquier cadena larga y aleatoria
  # En despliegue real cambia también POSTGRES_PASSWORD y MINIO_ROOT_PASSWORD.

3) Levantar el stack y crear el esquema:

  docker compose up -d --build
  docker compose exec backend alembic upgrade head

4) Verificar:

  curl http://localhost:8000/health        # -> {"status":"ok"}

  Servicios (puertos por defecto en Ubuntu limpio):
    backend    :8000   (API FastAPI; OpenAPI en http://localhost:8000/docs)
    db         :5432   (Postgres 15 + TimescaleDB)
    minio      :9000   (API S3)  /  :9001 (consola web, admin/admin123456)
    mosquitto  :1883   (broker MQTT)

  Comandos útiles:
    docker compose ps                      # estado
    docker compose logs -f backend         # logs del backend
    docker compose down                    # apagar (conserva datos en volúmenes)
    docker compose down -v                 # apagar y BORRAR datos (¡destructivo!)

--- OJO: puertos ---------------------------------------------------------
  Por defecto el stack usa 5432 (Postgres) y 8000 (backend). Si esos puertos
  están ocupados por OTRO proyecto (p. ej. contenedores 'dbjaguar'/'jaguar'),
  crea un pythonServer/docker-compose.override.yml LOCAL que los remapee. Ese
  override es local de cada máquina y NO forma parte del proyecto.
    -> En una máquina limpia usa 5432/8000 por defecto (sin override).

--- Nota de arranque -----------------------------------------------------
  app/settings.py debe tener  extra = "ignore"  en su clase Config. El .env es
  compartido con Postgres/MinIO (tiene POSTGRES_USER, MINIO_ROOT_*, etc.) y sin
  esa línea pydantic v2 aborta el arranque con "Extra inputs are not permitted".
  (Ya está en el código; solo tenlo presente si el backend no levanta.)

---------------------------------------------------------------------------
 B. FIRMWARE (ESP32-C3) — solo si vas a flashear la placa
---------------------------------------------------------------------------

1) Instalar arduino-cli y el core ESP32:

  curl -fsSL https://raw.githubusercontent.com/arduino/arduino-cli/master/install.sh | sh
  sudo mv bin/arduino-cli /usr/local/bin/
  arduino-cli config init
  arduino-cli core update-index
  arduino-cli core install esp32:esp32       # incluye el ESP32-C3
  arduino-cli lib install ArduinoJson        # v6

2) Permiso del puerto serie (típico en Ubuntu):

  sudo usermod -aG dialout $USER
  # cierra sesión y vuelve a entrar

3) Crear ESP32_controller/sensible.h (no viene en el repo). El firmware usa dos
   símbolos: apSsid y apPassword (los consume WiFi.AP.create en el .ino).
   Plantilla:

       #ifndef _SENSIBLE
       #define _SENSIBLE
       // SSID del punto de acceso que crea el ESP32 (la red "SmartPlant").
       const char* apSsid = "SmartPlant";
       // Passphrase WPA2 del AP: 8-63 caracteres. CÁMBIALA.
       const char* apPassword = "cambia-esta-clave";
       #endif

4) Compilar y flashear (ajusta el puerto; suele ser /dev/ttyACM0 o /dev/ttyUSB0):

  arduino-cli compile --fqbn esp32:esp32:esp32c3 ESP32_controller
  arduino-cli upload -p /dev/ttyACM0 --fqbn esp32:esp32:esp32c3 ESP32_controller

  Monitor serie (para ver los logs de printSystemData a 115200 baud):
  arduino-cli monitor -p /dev/ttyACM0 -c baudrate=115200

5) Usar el portal: conéctate a la red Wi-Fi "SmartPlant" desde el celular/PC;
   el portal captivo abre el formulario solo (gateway 192.168.4.1).

---------------------------------------------------------------------------
 C. PORTAL WEB (no requiere setup aparte)
---------------------------------------------------------------------------

  El portal es un único HTML embebido que sirve el firmware. Se edita el fuente
  HTML/mainForm.html y se REGENERA el artefacto que sirve el ESP32:

    python3 scripts/gen_mainform.py        # desde la raíz del proyecto

  Genera ESP32_controller/mainForm.h. Nunca se edita el .h a mano.
  Para validar el JS tras editar (opcional, requiere node):
    # extraer <script> y correr: node --check

---------------------------------------------------------------------------
 Resumen de lo mínimo para "solo el backend corriendo"
---------------------------------------------------------------------------
  cd pythonServer
  cp .env.example .env         # y cambia JWT_SECRET_KEY
  docker compose up -d --build
  docker compose exec backend alembic upgrade head
  curl http://localhost:8000/health

  Roadmap declarado, aún abierto

  * gzip del portal. handleRoot sigue sirviendo texto plano. Dato colateral: el artefacto está
  en ~73 KB, no en los ~49 KB que dicen el README y ARCHITECTURE.md — esa cifra quedó
  desactualizada.

Sensores de temperatura/humedad.
  
  Deuda y limpieza

  - Constantes muertas: intervalToSend, buzzerOn, buzzerOff.
  - El buzzer tiene pin y constantes pero está comentado y sin implementar.
  
Estoy haciendo un proyecto de esp32 c3 que controla un cultivo hidroponico. Las principales salidas son 3 pines para controlar ventilador, bomba y lampara led blanca, yotras 2 importantes son 2 pines pwm para controlar arreglos leds dimeables a 1KHz. Mi duda es la etapa de potencia, que componentes usar para poder activar relevadores y mosfets respectivamente. No se si las bobinas de los relevadores serán de DC o AC, y por eso aun no puedo decidir que tipo de optoacoplador elegir. Quiero algo que pueda conseguir facilmente, economico y que no necesite circuitos de control complicados, lo mismo para los mosfets. Lo ideal sería que pueda conseguirlos rapidamente con cualquier distribuidor autorizado, o que puedan ser suministrados con mis PCB's a traves del servicio de jlcpcb por ejemplo. Lo que venden localmente en mi ciudad, muchas veces está etiquetado como obsoleto con vendedores como mouser o digikey,

GEMINI

Para tu proyecto con el ESP32-C3, el principal reto es que sus pines digitales operan a 3.3V y tienen una corriente de salida máxima baja. Necesitas etapas de potencia que se activen con total seguridad a este voltaje y que estén disponibles en el catálogo básico (Basic Parts) de JLCPCB o distribuidores globales para evitar componentes obsoletos.
Aquí tienes la solución más económica, comercial y fácil de implementar, dividida por cada tipo de salida.
------------------------------
## 1. Etapa para los Mosfets (Tiras LED Dimeables a 1 kHz)
Para controlar arreglos LED dimeables mediante PWM a 1 kHz, no uses optoacopladores. A esa frecuencia, un optoacoplador común (como el PC817) es demasiado lento y deformará la señal, haciendo que los LEDs parpadeen o no apaguen por completo.
La mejor opción es usar un Mosfet de nivel lógico (Logic-Level) de canal N, diseñado para abrirse por completo con los 3.3V del ESP32-C3.

* Componente recomendado: AO3400A (Montaje superficial SMT, encapsulado SOT-23) o IRLZ44N (Si prefieres montaje de inserción Thru-Hole, encapsulado TO-220).
* Por qué elegirlo: El AO3400A es una "Pieza Básica" en JLCPCB, extremadamente económica y se activa totalmente con menos de 2.5V en la compuerta (Gate). Soporta hasta 30V y 5.7A, ideal para tiras LED de 12V o 24V.
* Circuito de control: Muy simple. Conecta el pin del ESP32 directamente a la compuerta (Gate) del Mosfet a través de una resistencia de 100 ohms (para proteger el pin). Coloca una resistencia de pulso a tierra (Pull-down de 10k ohms) entre la compuerta y GND para asegurar que los LEDs permanezcan apagados mientras el ESP32 se enciende.

------------------------------
## 2. Etapa para Relevadores (Ventilador, Bomba y Lámpara)
Para activar las bobinas de los relevadores, siempre debes usar bobinas de Corriente Directa (DC) (típicamente de 5V o 12V, dependiendo de la fuente de alimentación que uses para tu circuito). Controlar la bobina con AC complicaría innecesariamente tu PCB. Los contactos del relevador (la salida) sí controlarán los aparatos de AC (110V/220V) de tu cultivo.
Para proteger el ESP32-C3 de ruidos eléctricos provocados por la bomba y los motores, la optoaislación es altamente recomendada.
## Opción A: La solución clásica con Optoacoplador (Totalmente aislada)

* Optoacoplador: PC817 (o su versión SMD EL817). Es el más común del mundo, ultra barato y disponible en cualquier tienda local o JLCPCB.
* Activador de la bobina: El optoacoplador por sí solo no puede corriente suficiente para activar la bobina del relevador. Necesitas un transistor intermedio. Se usa el un transistor NPN común como el S8050 o 2N2222.
* Circuito de control: El pin del ESP32 enciende el LED interno del PC817 (usa una resistencia de 330 ohms). El transistor de salida del PC817 activa la base del transistor S8050, el cual finalmente energiza la bobina del relevador. Indispensable: Coloca un diodo de protección en paralelo con la bobina del relevador (como el 1N4148 o 1N4007) para absorber los picos de voltaje al apagarla.

## Opción B: Integrado Darlington (La más limpia y económica para JLCPCB)
Si no requieres aislamiento óptico estricto pero quieres ahorrar espacio y componentes:

* Componente recomendado: ULN2003A o TBD62003APG.
* Por qué elegirlo: Es un circuito integrado que contiene 7 canales de transistores listos para manejar relevadores. Ya incluye los diodos de protección internos. Puedes conectar los pines del ESP32-C3 directamente a las entradas del ULN2003, y las salidas directo a los relevadores de 5V o 12V. Es una pieza estándar global que jamás estará obsoleta.

------------------------------
## Resumen de Selección de Componentes

| Salida | Componente Clave | Tipo / Encapsulado | Función en el circuito | Disponibilidad en JLCPCB |
|---|---|---|---|---|
| PWM (LEDs) | AO3400A | Mosfet N-Chan (SOT-23) | Conmutación rápida a 1kHz con señal de 3.3V. | Alta (Pieza Básica) |
| Relevador | PC817 / EL817 | Optoacoplador (DIP-4 / SOP-4) | Aislar eléctricamente el ESP32 de los ruidos. | Alta (Pieza Básica) |
| Relevador | S8050 o 2N2222 | Transistor NPN (SOT-23 / TO-92) | Amplificar la corriente para activar la bobina. | Alta (Pieza Básica) |
| Protección | 1N4148 o 1N4007 | Diodo (SOD-123 / DO-35) | Diodo volante (Flyback) para la bobina. | Alta (Pieza Básica) |

Para ayudarte a cerrar el diseño de tu circuito, ¿podrías decirme:

* ¿A qué voltaje operan tus arreglos de LEDs dimeables (12V, 24V o corriente constante)?
* ¿De qué voltaje planeas alimentar la etapa de control y las bobinas de los relevadores (ej. usarás una fuente de 5V o de 12V)?

Con esto te puedo compartir los diagramas exactos de conexión con los valores de las resistencias.

CHATGPT

Tu arquitectura puede ser bastante sencilla. **Yo evitaría diseñar la etapa alrededor de optoacopladores hasta decidir si realmente necesitas aislamiento galvánico**. Para un ESP32-C3, en la mayoría de estos casos puedes hacer una etapa de potencia con MOSFETs directamente desde GPIO y reservar los optoacopladores para las partes que realmente estén conectadas a red eléctrica.

Además, hay una decisión de diseño que te simplifica muchísimo el proyecto: **elige relevadores con bobina DC**, preferentemente de 5 V o 12 V, aunque sus contactos puedan conmutar cargas AC de 120/230 V.

## 1\. Arquitectura que te recomendaría

Para tus 5 salidas:

```
                         ESP32-C3
                            │
              ┌─────────────┼─────────────┐
              │             │             │
          GPIO RELAY    GPIO PWM       GPIO PWM
              │             │             │
              ▼             ▼             ▼
        Driver MOSFET    MOSFET N       MOSFET N
              │             │             │
          Bobina relay   LED array 1   LED array 2
              │
           +5/+12 V
```

Y para ventilador/bomba/lámpara:

```
ESP32 GPIO
    │
    ├── 100 Ω
    │
    ▼
  Gate
   ┌───┐
   │ N │ MOSFET
   └─┬─┘
     │
     ├──────── carga
     │
    GND
```

Si esas cargas son, por ejemplo, **ventiladores/bombas de 12/24 V DC**, ni siquiera necesitas un relevador: puedes usar MOSFET directamente.

Si son cargas de **120/230 VAC**, entonces sí usaría relevadores.

---

# 2\. Para los relevadores: usa bobinas DC

Esta es probablemente la decisión más importante.

Un relevador puede tener:

- bobina de 5 V DC
- bobina de 12 V DC
- bobina de 24 V DC
- bobina de 120 VAC
- bobina de 230 VAC

Pero **para tu PCB yo escogería deliberadamente uno de 5, 12 o 24 V DC**.

Por ejemplo:

- TE Connectivity PCB Power Relay 5V DC CoilMX$61.72LionCircuits + others★ 5

Un relevador con bobina DC se puede controlar así:

```
              +12 V
                │
                │
             BOBINA
                │
                ├─────────|<|──────── +12 V
                │        Diodo
                │
              Drain
                │
             MOSFET
                │
              Source
                │
               GND
```

El ESP32 solamente controla el **gate**.

### MOSFET para la bobina

Aquí no necesitas nada sofisticado.

Por ejemplo:

- 2N7002
- BSS138
- AO3400A
- IRLML2502
- Si2302

De esos, **AO3400A sería uno de mis favoritos para tu proyecto** si quieres algo muy común y con bastante margen.

- AO3400A MOSFETMX$0.36Richard Electronics★ 5

El 2N7002 también es extremadamente común:

- MMBT7002K-AQMX$3.06DigiKey Mexico

Pero el 2N7002 tiene bastante menos capacidad de corriente. Para una bobina pequeña puede funcionar perfectamente; para hacer una PCB más universal, prefiero AO3400A.

---

# 3\. El circuito de cada relevador

Yo haría esto:

```
ESP32 GPIO
    │
   100Ω
    │
    ├──────── Gate
    │           │
    │         AO3400A
    │           │
   100kΩ       │
    │          │
   GND       Source
               │
              GND

+12V ──────── BOBINA ─────── Drain
                  │
                  │
             ┌────┴────┐
             │  Diodo  │
             └────┬────┘
                  │
                 +12V
```

El diodo va **en paralelo con la bobina y en polarización inversa durante funcionamiento normal**.

Por ejemplo:

- 1N4148 para bobinas pequeñas
- 1N4007 para algo más robusto
- SS14 si quieres un diodo Schottky SMD

Yo pondría **SS14 o 1N4007** si no tienes una razón concreta para usar otra cosa.

### Valores

Para cada MOSFET:

- `Rgate = 47–220 Ω`
- `Rpulldown = 47–100 kΩ`

Una combinación muy conservadora:

```
GPIO ─── 100Ω ─── Gate
                  │
                 100k
                  │
                 GND
```

El pulldown garantiza que el relevador permanezca apagado mientras el ESP32 está arrancando.

Esto es particularmente importante porque el ESP32-C3 tiene estados de GPIO durante reset/boot que no deberías utilizar como garantía de que una carga permanezca apagada. El C3 funciona a 3.3 V y sus especificaciones de GPIO son compatibles con este tipo de control; Espressif especifica, entre otras cosas, `VOH ≥ 0.8×VDD` y un límite de salida de corriente bastante superior a lo que necesitamos aquí.  Espressif Documentation+1

---

# 4\. ¿Necesitas optoacoplador para los relevadores?

**No necesariamente.**

Este punto suele complicar innecesariamente los diseños con ESP32.

Si tienes:

```
ESP32
 │
 │ GPIO
 ▼
MOSFET
 │
 ▼
Bobina 12 V
```

y compartes GND entre la fuente de 12 V y la electrónica del ESP32, no necesitas aislamiento.

Pero si tienes:

```
ESP32
      │
      │  aislamiento
      ▼
   potencia
      │
      ▼
  red eléctrica
```

entonces el aislamiento puede tener mucho sentido.

### Si quieres aislamiento

Un PC817/EL817 es una opción extremadamente común y económica.

- SHARP PC817MX$9.71JAK Electronics★ 5

También hay variantes SMD:

- PC817 SMDMX$3.60JAK Electronics★ 5

Pero **yo no pondría un PC817 simplemente porque "es buena práctica"**. Añade:

- opto
- resistor LED
- resistor pull-up
- posiblemente otro transistor
- más componentes
- más espacio
- más cosas que pueden fallar

Para tus MOSFET PWM de 1 kHz, además, tampoco veo una razón para meter un PC817 entre el ESP32 y el MOSFET.

---

# 5\. Tus dos salidas PWM de 1 kHz son otro asunto

Aquí sí recomiendo claramente:

**ESP32 → MOSFET → LEDs**

No:

**ESP32 → opto → MOSFET**

El ESP32-C3 tiene periférico LED PWM (LEDC), así que 1 kHz es una frecuencia perfectamente razonable para generar PWM.  Espressif Documentation

La etapa puede ser:

```
                    +V LED
                      │
                      │
                 LED ARRAY
                      │
                      │
                    Drain
                 ┌────────┐
PWM ── 100Ω ────►│ AO3400A│
                 └────────┘
                    Source
                      │
                     GND
```

Con:

```
GPIO ── 100Ω ── Gate
                │
               100k
                │
               GND
```

Para 1 kHz, esto es trivial para un MOSFET moderno.

---

# 6\. Pero aquí hay una pregunta MUY importante: ¿cómo alimentas los LEDs?

Necesito distinguir entre estas dos situaciones:

### Caso A — LEDs ya tienen driver de corriente

Por ejemplo:

```
24 V
 │
 Driver LED
 │
 LED array
```

Entonces puedes controlar el driver dependiendo de qué entrada tenga:

- PWM
- enable
- dimming
- 0–10 V

### Caso B — tu arreglo LED es simplemente LEDs + resistencias

Por ejemplo:

```
24 V
 │
 resistor
 │
 LED
 │
 resistor
 │
 LED
 │
 MOSFET
 │
GND
```

Entonces el MOSFET puede funcionar muy bien como interruptor PWM.

### Caso C — arreglo LED de alta potencia

Por ejemplo 20 W, 50 W, 100 W...

Aquí **no recomiendo simplemente conectar el arreglo a un MOSFET y una fuente de voltaje**.

Necesitas conocer:

- tensión de alimentación
- corriente
- potencia
- si los LEDs tienen resistencia
- si tienen driver de corriente constante
- corriente máxima deseada

Y el MOSFET se selecciona en función de eso.

---

# 7\. Para tus dos MOSFET PWM, AO3400A es una muy buena primera opción

Para una PCB económica y fácil de fabricar, yo empezaría investigando:

### AO3400A

Ventajas:

- N-channel
- SMD SOT-23
- muy común
- barato
- adecuado para control lógico
- funciona bien con GPIO de 3.3 V
- excelente para cargas pequeñas/medianas
- fácil de conseguir

Para cargas mayores, cambiaría a un MOSFET con menor `RDS(on)` y mayor corriente.

**No elegiría el MOSFET únicamente por "60 V / 30 A".**

Para este diseño importan mucho:

```
RDS(on) @ VGS = 2.5 V o 3.3 V
```

porque tu ESP32 no le está dando 10 V al gate.

Ese detalle es muy importante.

---

# 8\. Y aquí hay una ventaja enorme de diseñar tu PCB de forma modular

Puedes hacer la huella para un MOSFET SOT-23 bastante común:

```
       G
       │
    ┌─────┐
 D──┤     │
 D──┤     │
 S──┤     │
    └─────┘
```

y utilizar:

- AO3400A
- AO3400
- Si2302
- otros equivalentes compatibles

dependiendo de disponibilidad.

Esto te protege muchísimo contra problemas de suministro.

Lo mismo con el optoacoplador: si finalmente lo necesitas, puedes dejar una huella estándar de **4 pines** compatible con PC817/EL817 y variantes equivalentes.

---

# 9\. Yo cambiaría una cosa de tu planteamiento: no hagas que los relevadores sean necesariamente las salidas principales

Si tu cultivo tiene:

- ventilador DC
- bomba DC
- lámpara LED DC

y solamente ocasionalmente vas a controlar una carga AC, sería mejor:

```
                ESP32-C3
                   │
       ┌───────────┼───────────┐
       │           │           │
       ▼           ▼           ▼
    MOSFET       MOSFET      MOSFET
       │           │           │
   ventilador     bomba     LED blanco
```

Y:

```
             ESP32-C3
                 │
                 ▼
              MOSFET
                 │
              RELAY
                 │
             120/230 VAC
```

Así los MOSFET manejan directamente las cargas DC y el relevador solamente aparece donde realmente necesitas aislamiento/contactos.

---

# 10\. ¿Y si la bomba o ventilador son AC?

Ahí cambia todo.

Si tienes:

```
ESP32 → MOSFET → bomba AC
```

**no.**

Un MOSFET N-channel convencional no es el interruptor adecuado para una carga AC de red.

Tendrías dos caminos principales:

### Opción 1 — Relevador

```
ESP32
 ↓
MOSFET
 ↓
bobina DC
 ↓
CONTACTOS
 ↓
AC
 ↓
bomba
```

Es mi opción favorita para un prototipo de hidroponía sencillo.

### Opción 2 — SSR/triac

```
ESP32
 ↓
opto
 ↓
triac/SSR
 ↓
AC
 ↓
bomba
```

Puede ser excelente para cargas AC, pero aumenta las consideraciones de diseño térmico, corriente de fuga, tipo de carga, cruce por cero, etc.

Para tu primera PCB probablemente elegiría **relevadores de bobina DC**.

---

# 11\. Sobre el optoacoplador y AC/DC de la bobina

Tu duda original era muy buena:

> "No sé si las bobinas de los relevadores serán DC o AC y por eso aún no puedo decidir qué optoacoplador elegir."

La solución es:

**no diseñes el circuito de control dependiendo de que la bobina sea AC o DC. Define tú el componente.**

Por ejemplo:

> "Mi PCB requiere relevadores con bobina de 12 VDC."

Entonces tu interfaz queda perfectamente definida:

```
GPIO 3.3 V
     │
    100Ω
     │
     ▼
 AO3400A
     │
     ▼
 Relay coil 12 VDC
     │
    GND
```

Y el **tipo de corriente de los contactos** es independiente:

```
Relay coil:       12 V DC

Relay contacts:   250 VAC / 10 A
```

Eso es precisamente lo que quieres.

---

# 12\. Componentes que pondría en mi BOM inicial

Para una primera versión, tendría algo parecido a esto:

| Función | Componente que probaría |
| --- | --- |
| MOSFET general | **AO3400A** |
| MOSFET pequeño | **2N7002** |
| Opto opcional | **PC817 / EL817** |
| Diodo bobina | **SS14 / 1N4007** |
| R gate | **100 Ω** |
| Pull-down gate | **100 kΩ** |
| Relay | **5/12 V DC coil** |
| PWM | **1 kHz desde LEDC** |
| Alimentación potencia | 12/24 V DC según cargas |

Y hay una razón adicional para preferir AO3400A frente al 2N7002 para la parte de potencia: quieres que el mismo diseño pueda tolerar cargas más grandes sin tener que rediseñar inmediatamente la etapa.

---

## 13\. Hay algo que todavía NO cerraría

Antes de dibujar el esquemático definitivo, me faltan **5 datos fundamentales de tus cargas**:

1. **Ventilador:** ¿12 V DC, 24 V DC o 120/230 VAC? ¿Cuántos amperios?
2. **Bomba:** ¿12 V DC, 24 V DC o AC? ¿Cuántos amperios?
3. **LED blanco:** ¿qué voltaje/corriente?
4. **Los dos arreglos LED PWM:** ¿voltaje y corriente máxima de cada uno?
5. **¿Qué tensión tendrás disponible para potencia?** ¿12 V, 24 V, ambas?

Con esos datos puedo proponerte **el esquemático completo de las 5 salidas**, incluyendo valores de resistencias, diodos, MOSFET específico, protección contra transitorios, conectores y separación entre la parte de **3.3 V / baja tensión y 120/230 VAC**. También puedo orientarlo para que sea razonablemente compatible con el ensamblado de JLCPCB y evitar componentes que sean difíciles de conseguir.

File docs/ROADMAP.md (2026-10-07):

# Roadmap — Migración del firmware a ESP-IDF

Plan de migración del firmware de **Arduino-ESP32** a **ESP-IDF** puro, por fases entregables y verificables en hardware por separado. La meta es profesionalizar el firmware (tooling, control de RAM/flash, OTA de doble slot y TLS), no aumentar la velocidad de CPU.

Para el diseño técnico a fondo, ver [ARCHITECTURE.md](ARCHITECTURE.md). `Constants.h` sigue siendo la fuente de verdad del hardware y los límites de validación.

---

## Motivación y expectativas honestas

Arduino-ESP32 **ya corre sobre ESP-IDF**: cuando el firmware llama `ledcAttachChannel`, `esp_random()`, `mbedtls_md_hmac` o `vTaskDelay`, ya está ejecutando código de IDF. La migración **no hace el firmware "más rápido"** —misma CPU (RISC-V @160 MHz), mismo compilador (`riscv32-esp-gcc`), y el cuello de botella real (servir ~73 KB de HTML y handlers HTTP esporádicos) no está limitado por CPU.

Lo que sí se gana, y por qué se migra:

| Beneficio | De dónde sale |
|---|---|
| **Menos flash y RAM** | `menuconfig` recorta componentes que Arduino incluye por defecto; buffers de red, stacks por tarea y config de mbedTLS ajustables |
| **OTA de doble slot con rollback** | `esp_ota_ops` / `esp_https_ota` + `partitions.csv` con dos slots OTA, de primera clase en IDF |
| **TLS con pinning y firmware firmado** | Control fino de mbedTLS y `esp_https_*`; el firmware ya usa `mbedtls/md.h` directo |
| **HTTP por chunks / gzip nativo** | `esp_http_server` resuelve por diseño el pico de heap que hoy se maneja con `send_P` |
| **Control de socket/interfaz** | `esp_wifi` + `esp_netif` reemplazan los workarounds actuales (bind del portal solo a la IP del AP) |

> El rendimiento del **backend** (Postgres/Timescale, índices, ingesta MQTT, pooling) es un tema separado que no depende de esta migración. Ver [BACKEND.md](BACKEND.md).

---

## Clasificación del código actual

Inventario de los 4 archivos del firmware según el esfuerzo de migración.

### Portable sin cambios de lógica (ya es IDF o es neutral)

| Elemento | Nota |
|---|---|
| `utils.cpp` / `utils.h` | Cripto (`mbedtls/md.h`, PBKDF2-HMAC-SHA256, comparación en tiempo constante, hex), BCD del RTC, validación UTF-8, aritmética de fechas. Solo cambia el tipo `String` en las firmas |
| Lógica de `Constants.h` | Enums, límites de validación, `validFrequencies`. Solo cambian `HIGH`/`LOW`, `IPAddress` y el `#include <Arduino.h>` |
| Lógica de negocio de `Plant.cpp` | Scheduling stateless, derivación de día/semana desde el RTC, validación, manejo del bit OSF del DS3231, sesión con token. **Es el valor real del proyecto y no depende de Arduino** |
| `ArduinoJson` (v6) | Funciona en IDF puro como componente; **no se reescribe** |

### Requiere reescritura (la capa de framework)

| API actual (Arduino) | Destino (ESP-IDF) | Esfuerzo |
|---|---|---|
| `Preferences` | `nvs_flash` / API `nvs` | Bajo (casi 1:1) |
| `Wire` (I²C DS3231) | `driver/i2c_master.h` | Bajo |
| `ledcAttachChannel`, `pinMode`, `digitalWrite` | `driver/ledc.h`, `driver/gpio.h` | Bajo |
| `WiFi.*` (AP+STA, scan, eventos) | `esp_wifi` + `esp_netif` + event loop | Medio |
| `DNSServer` | Servidor DNS captivo propio (~80 líneas, patrón conocido) | Medio |
| `WebServer` (10 handlers) | `esp_http_server` | Alto |
| `String` | `std::string` / `char[]` en toda la superficie | Medio (mecánico pero extenso) |

---

## Estrategia: incremental, no big-bang

Arduino-ESP32 puede compilarse **como componente dentro de un proyecto ESP-IDF**. Eso permite adoptar el tooling profesional (`idf.py`, `menuconfig`, `partitions.csv`, OTA, TLS) **sin reescribir todavía** `WebServer`/`String`. Cada fase queda funcional y verificable en hardware por separado; no hay un periodo largo con el portal roto.

---

## Fases

### Fase 0 — Build ESP-IDF con Arduino como componente

**Objetivo:** convertir el proyecto en un proyecto ESP-IDF sin reescribir lógica. Es el paso que desbloquea OTA y TLS con el mínimo riesgo.

- [ ] Estructura de proyecto IDF: `CMakeLists.txt` raíz, `main/CMakeLists.txt`, `sdkconfig.defaults`
- [ ] Integrar `arduino-esp32` como componente (managed component o submódulo)
- [ ] Mover el sketch a `main/` y adaptar `setup()`/`loop()` al `app_main()` (o `initArduino()` + task)
- [ ] `partitions.csv` con **dos slots OTA** (`ota_0`, `ota_1`) + `otadata` + `nvs`
- [ ] Compilar con `idf.py build` y flashear con `idf.py flash`
- [ ] Recorte inicial de componentes en `menuconfig`

**Verificación:** el portal arranca y funciona idéntico al build de Arduino (registro, login, edición, Wi-Fi, RTC). Medir flash/RAM antes y después.

**Criticidad de `partitions.csv`:** OTA de doble slot exige dos particiones de app del mismo tamaño. Fijar esto ahora evita rehacer el layout más adelante. Ver [ARCHITECTURE.md § requisito de particiones](ARCHITECTURE.md#requisito-crítico-tabla-de-particiones-con-dos-slots-ota).

> El proyecto **Arduino actual ya incluye** `ESP32_controller/partitions.csv` con dos slots OTA (4 MB: `nvs` 20 KB, `otadata`, dos slots de ~1.94 MB con `ota_0` en el offset estándar `0x10000`), creado para el OTA local. La migración a IDF puede reutilizar ese layout como punto de partida.

---

### Fase 1 — Periféricos a IDF nativo

**Objetivo:** migrar los periféricos de bajo acoplamiento. No toca la capa HTTP.

- [ ] NVS: `Preferences` → API `nvs` (namespaces `system`, `plantData`, `config`, `wifi`)
- [ ] I²C DS3231: `Wire` → `driver/i2c_master.h` (lectura de 7 bytes, registro OSF `0x0F`)
- [ ] PWM/GPIO: `ledcAttachChannel` → `driver/ledc.h`; `pinMode`/`digitalWrite` → `driver/gpio.h`

**Verificación:** luces (PWM azul/rojo + blanco ON/OFF), bomba y ventilador responden igual; la hora del RTC se lee y el modo seguro por OSF sigue activo; la config persiste tras reinicio.

> Al cambiar el esquema de persistencia, respetar la nota de `Constants.h`: `_systemStatus` se guarda por índice; borrar la flash antes de cargar el firmware nuevo si cambia el layout.

---

### Fase 2 — Wi-Fi a `esp_wifi` / `esp_netif`

**Objetivo:** reemplazar la abstracción de `WiFi` y recuperar el control fino de interfaz/socket.

- [ ] AP+STA con `esp_wifi` + `esp_netif` + event loop (`WIFI_EVENT` / `IP_EVENT`)
- [ ] SoftAP WPA2-PSK (credenciales en `sensible.h`); STA condicional si hay credenciales en NVS
- [ ] Escaneo asíncrono (5 más fuertes, sin SSID repetidos)
- [ ] Persistencia diferida de credenciales (solo al llegar a `WL_CONNECTED` equivalente)
- [ ] Desactivar modem-sleep para que el AP responda estable en AP+STA

**Verificación:** el portal responde solo por la interfaz del AP (no por STA); el escaneo devuelve la lista; conectar a la Wi-Fi del usuario y confirmar por polling; las credenciales inválidas no se persisten.

---

### Fase 3 — HTTP a `esp_http_server` + DNS captivo propio

**Objetivo:** el trabajo grande. Sincronizar con la homologación del **Portal V2**, porque esa capa se toca de todas formas.

- [ ] `esp_http_server`: los 10 endpoints (`/`, `/usercredentials`, `/getparams`, `/newparams`, `/newcrop`, `/authusercredentials`, `/wifiscan`, `/wificredentials`, `/exit`, `onNotFound`)
- [ ] Servir el portal por **chunks** desde flash (`httpd_resp_send_chunk`) — resuelve el pico de heap por diseño
- [ ] **gzip** (`Content-Encoding: gzip`) para el portal — **ya implementado en Arduino**
      (`gen_mainform.py` comprime y `handleRoot` sirve con el encabezado); aquí solo se
      portaría el mismo esquema a IDF al migrar `handleRoot`.
- [ ] Autorización del reset por interfaz de AP (equivalente a comparar la IP local del socket con la del SoftAP)
- [ ] Servidor DNS captivo propio (responde la IP del AP a todas las consultas)
- [ ] Endpoint **`POST /otaupdate`** (subir `.bin` por el AP) usando `esp_ota_ops`

**Verificación:** todos los endpoints responden igual que hoy (contrato de [API.md](API.md)); el portal carga completo en AP+STA sin fallos de heap; el reset solo se acepta por el AP; un OTA local completa y arranca el binario nuevo.

---

### Fase 4 — Eliminar `String` (IDF puro)

**Objetivo:** cierre. Quitar la última dependencia de Arduino.

- [ ] `String` → `std::string` / `char[]` en handlers, `buildParamsJson`, `scanNetworks`, `HttpResponse`
- [ ] Firmas de `utils.*` sin `String`
- [ ] Quitar el componente `arduino-esp32` del build
- [ ] Recorte final de componentes en `menuconfig`

**Verificación:** compila sin `arduino-esp32`; suite de pruebas en hardware completa; comparar flash/RAM contra la Fase 0.

---

### Fase 5 — OTA segura sobre TLS

**Objetivo:** cerrar la seguridad del canal de actualización. Depende de las fases anteriores.

- [ ] `esp_https_ota` con **CA pinning**
- [ ] **Firmware firmado** (secure boot / verificación de firma de imagen)
- [ ] **Rollback automático si la imagen nueva no arranca** — hoy NO existe: el OTA local
      reinicia directo al binario nuevo sin "marcado de app válida", así que un `.bin`
      estructuralmente válido pero no arrancable puede brickear el equipo (ver
      [ARCHITECTURE.md § OTA](ARCHITECTURE.md#endpoint-post-otaupdate)). Requiere
      `esp_ota_mark_app_valid_cancel_rollback()` + `CONFIG_BOOTLOADER_APP_ROLLBACK_ENABLE`
      (de primera clase en IDF).
- [ ] Integración con el endpoint OTA del backend (ver [BACKEND.md](BACKEND.md))

> **Mitigación de corto plazo (no requiere IDF):** verificar el **hash** del binario en el
> OTA local — el cliente envía el SHA/MD5 y el firmware lo fija con `Update.setMD5(...)`;
> `Update.end()` falla si no coincide. Restringe a binarios aprobados y atrapa corruptos, sin
> esperar a la firma criptográfica. No sustituye al rollback, pero reduce el riesgo de subir
> un binario equivocado.

**Verificación:** un OTA con imagen firmada válida completa y persiste; una imagen no firmada o con CA incorrecta se rechaza; el rollback restaura el slot anterior ante fallo de arranque.

---

## Orden recomendado y criterios de avance

1. **Fase 0 primero** — desbloquea OTA/TLS con el mínimo riesgo y valida el tooling antes de reescribir nada crítico.
2. Fases 1 y 2 a ritmo propio; son cambios acotados y verificables.
3. **Fase 3 sincronizada con el Portal V2** — no duplicar el trabajo de la capa de servido.
4. Fases 4 y 5 al final.

**Regla de avance:** no empezar una fase hasta que la anterior esté verificada en hardware y medida (flash/RAM cuando aplique). Cada fase debe dejar el dispositivo en un estado funcional y flasheable.

---

## Estado

| Fase | Descripción | Estado |
|---|---|---|
| 0 | Build IDF + Arduino como componente + `partitions.csv` doble slot | No iniciada |
| 1 | Periféricos a IDF nativo (NVS, I²C, LEDC/GPIO) | No iniciada |
| 2 | Wi-Fi a `esp_wifi` / `esp_netif` | No iniciada |
| 3 | HTTP a `esp_http_server` + DNS captivo + OTA local | No iniciada |
| 4 | Eliminar `String` (IDF puro) | No iniciada |
| 5 | OTA segura sobre TLS (pinning + firma) | No iniciada |

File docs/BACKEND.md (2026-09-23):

# Backend SmartPlant — Diseño y guía de arranque

> **Propósito de este documento.** Fijar las decisiones de arquitectura del backend
> para que la próxima sesión (humana o IA) pueda **arrancar la implementación sin
> recontexto**. Todo lo que sigue está **confirmado** salvo lo marcado explícitamente
> como "pendiente". Complementa la sección *"Modelado de la base de datos (backend
> futuro)"* y *"TLS en el ESP32-C3"* de [`ARCHITECTURE.md`](ARCHITECTURE.md), que
> siguen siendo la referencia del lado del firmware.

> **Estado: auth, provisión, config/telemetría y lecturas app-facing implementados y
> verificados end-to-end.** La infraestructura local corre con `docker compose up -d --build`.
> Alembic administra el esquema (migración `001` aplicada: extensión, 5 tablas, hypertable,
> índices). Verificado contra el stack real:
> - **Auth** (`register`, `login`, `refresh`) con JWT + bcrypt.
> - **Provisión** (`POST /devices/provision`): emite el token de dispositivo y persiste solo su hash.
> - **Config y telemetría** (`POST /devices/{id}/config`, `POST /devices/{id}/telemetry`),
>   autenticadas por token de dispositivo (`app/deps.py`): config inserta histórico, telemetría
>   fija `ts` en servidor y refresca `last_seen_at`/`firmware_version`, y los casos negativos
>   401/400 responden.
> - **Lecturas app-facing** (`GET /me/devices`, `GET /devices/{id}/state`, `GET /devices/{id}/telemetry`)
>   con aislamiento por cuenta.
>
> **Pendiente:** OTA (`/firmware/latest`, admin de releases), rutas de admin, e ingesta por MQTT.
>
> Decisiones cerradas:
> - **Broker: Mosquitto** (no EMQX). Ver el [caveat de autenticación MQTT](#caveat-mosquitto-no-autentica-contra-la-base-de-datos).
> - **Identificador de usuario: `email`** (`UNIQUE NOT NULL`).
> - **Dueño del esquema: Alembic.** El compose **no** aplica `schema.sql`; la primera
>   migración crea extensión, tablas e hypertable.

---

## 1. Qué resuelve el backend

Cuatro requisitos, cada uno mapeado a una pieza del stack:

| Requisito | Naturaleza técnica | Pieza que lo resuelve |
|---|---|---|
| Persistir estado/config + variables de cultivo | Config (relacional) + telemetría (serie temporal) | Postgres + **TimescaleDB** |
| Dispositivos asociados a un usuario/cuenta | Multi-tenant simple (1:N) | Modelo relacional + JWT |
| Exponer binarios de firmware (OTA) | Archivos grandes, versionados, firmados | **Object storage S3-compatible** + tabla catálogo |
| Exponer histórico a móviles/tablets | API de lectura autenticada | **REST/HTTPS (FastAPI)** + JWT |

---

## 2. Decisiones confirmadas (el stack)

| Decisión | Valor | Notas |
|---|---|---|
| **Lenguaje/API** | **FastAPI (Python)** | Async, OpenAPI automático (clave para que móvil/tablet consuman sin fricción), Pydantic para validar payloads |
| **Base de datos** | **PostgreSQL + TimescaleDB** | Un solo motor: relacional + serie temporal. Hypertables, compresión, *continuous aggregates*, *retention policies* |
| **Ingesta de telemetría** | **MQTT** (broker **Mosquitto**) | Conexión persistente: amortiza el costoso handshake TLS del C3. REST/HTTPS solo para acciones puntuales. Ver [caveat de auth](#caveat-mosquitto-no-autentica-contra-la-base-de-datos) |
| **Storage OTA** | **S3-compatible**: **MinIO** local + **S3** en nube | Misma API (`aioboto3`); solo cambia `endpoint_url`. Binarios fuera de la BD |
| **Auth apps** | **JWT propio** (access + refresh) | `1 usuario = 1 cuenta` identificada por **`email`**; login simple, sin proveedor gestionado |
| **Auth dispositivos** | Token de dispositivo revocable | Aprovisionamiento `email+pass+mac` sobre TLS → backend emite token; se guarda `token_hash` |
| **ORM / migraciones** | **SQLAlchemy + Alembic** | Default de FastAPI |
| **Reverse proxy / TLS** | **Caddy** o **Traefik** | TLS/Let's Encrypt automático; el app **nunca** termina TLS directo |
| **Empaquetado** | **Docker** (compose para local) | Corre idéntico en servidor propio y en nube |

**Regla de oro que atraviesa todo:** el lenguaje del API es **solo una** de las piezas.
Postgres/Timescale, MQTT, object storage, JWT y el proxy son **idénticos** en servidor
propio o en nube; lo que cambia es la configuración (ver §6), no el código.

---

## 3. Modelo de datos (final)

Cardinalidades confirmadas:
- **1 usuario = 1 cuenta** → `users` y `accounts` colapsan en **una sola tabla** `users`.
- **1 usuario → N dispositivos**; **1 dispositivo → exactamente 1 usuario** (relación
  1:N; la FK vive en `devices`).

```
users (1) ──────< (N) devices
                        ├──< device_configs    (histórico de config)
                        └──< device_telemetry   (serie temporal → hypertable)

firmware_releases   (catálogo OTA; el binario vive en object storage, no en la BD)
```

| Tabla | Campos clave | Notas |
|---|---|---|
| `users` | `id`, `email` (UNIQUE), `password_hash`, `is_admin`, `created_at` | Cuenta = persona. Hash con **bcrypt/argon2**. `is_admin` (default `false`) habilita las rutas `/admin/*` (publicar firmware). Ver §6 |
| `devices` | `id`, `mac` (UNIQUE), `user_id` (FK → users, **NOT NULL**), `name`, `token_hash`, `firmware_version`, `last_seen_at`, `created_at` | La MAC identifica; `token_hash` = token de dispositivo hasheado (revocable) |
| `device_configs` | `id`, `device_id` (FK), `planta`, `enable`, `fp_on`, `fp_off`, `led_a/r/b`, `irr_h/m`, `vent_h/m`, `crop_start_day`, `applied_at` | **Una fila por cambio** (histórico). La última = config vigente. **Espeja las llaves de `/newparams`** del firmware |
| `device_telemetry` | `id`, `device_id` (FK), `ts`, `temp`, `humidity`, `firmware_version`, `wifi_rssi`, `uptime` | **Serie temporal → hypertable de TimescaleDB**. `temp`/`humidity` = lecturas de sensor (°C / % HR). `firmware_version` se estampa en cada lectura para correlacionar datos con la versión que los produjo |
| `firmware_releases` | `version`, `url`, `sha256`, `signature`, `min_version`, `published_at` | Catálogo para OTA. `url` apunta al object storage |

**Autorización (trivial gracias a 1:N):** cada request de la app trae el JWT del
usuario → *"¿`device.user_id` == `user.id` del token?"*. Una sola condición, sin
joins de permisos ni tabla de membresías.

> Las llaves de `device_configs` deben mantenerse en sync con el payload de
> `/newparams` del firmware (ver [`API.md`](API.md) y `Plant.cpp`). Si cambia
> el formulario del portal, cambia esta tabla.

> **`firmware_version` aparece en dos lugares a propósito, no por error:**
> `devices.firmware_version` guarda la versión **vigente** del dispositivo (para
> decidir OTA en `/firmware/latest?current=X`); `device_telemetry.firmware_version`
> estampa la versión **en cada lectura**, para poder analizar el histórico sabiendo
> qué firmware lo produjo (p. ej. detectar que un sensor empezó a reportar raro tras
> una actualización).

---

## 4. Contratos de la API

Tres superficies con esquemas de autenticación distintos. Convenciones comunes:

- Todo es JSON con `Content-Type: application/json`, salvo la subida de firmware (multipart).
- Errores con el formato de FastAPI: `{"detail": "<mensaje>"}` y el código HTTP correspondiente.
- Los timestamps son **ISO 8601 con zona** (`2026-08-24T17:04:00-06:00`).
- `{id}` en las rutas es `devices.id` (entero), no la MAC.

### 4.0 Cómo se autentican los dispositivos

Un dispositivo **no** guarda la contraseña del usuario. El flujo tiene dos fases:

**Fase 1 — provisión (una sola vez).** El usuario introduce sus credenciales en el portal
local del ESP32; el dispositivo las manda con su MAC a `POST /devices/provision` sobre TLS.
El backend valida la cuenta, crea o vincula la fila en `devices` y **emite un token de
dispositivo**. Es el único momento en que la contraseña del usuario viaja por la red.

**Fase 2 — operación (siempre).** El dispositivo se autentica con ese token en cada
petición, vía `Authorization: Bearer <token>`.

En la base se guarda **solo `devices.token_hash`** (bcrypt, igual que una contraseña): si se
filtra la BD, nadie obtiene credenciales funcionales. Y como el token vive en una fila, es
**revocable**: se borra o se rota y el dispositivo queda fuera hasta re-provisionarse.

> **No confundir con el token de sesión del firmware.** Son dos cosas distintas:
>
> | | Sesión del portal ([`API.md`](API.md)) | Token de dispositivo (este doc) |
> |---|---|---|
> | Vive en | RAM del ESP32 | `devices.token_hash` |
> | Sirve para | Editar parámetros en la red local | Hablar con la nube |
> | Vigencia | 30 min fijos, muere al reiniciar | Hasta que se revoque |
> | Lo emite | El propio dispositivo | El backend |

### 4.1 Device-facing (ESP32-C3 → backend)

Autenticadas con el **token de dispositivo**, salvo `/devices/provision`.

#### `POST /devices/provision`

```json
{ "email": "usuario@ejemplo.com", "pass": "miClave123", "mac": "A1:B2:C3:D4:E5:F6" }
```

`201` — el `token` se devuelve **una sola vez**; no hay endpoint para recuperarlo.

```json
{ "device_id": 12, "token": "<64 hex>", "name": null }
```

`401` credenciales inválidas · `409` la MAC ya está vinculada a otra cuenta.

#### `POST /devices/{id}/config`

Registra la configuración vigente del cultivo. Las llaves **espejan las del firmware**
(ver [`API.md`](API.md)), en `snake_case`.

```json
{
  "planta": "Albahaca", "enable": true,
  "fp_on": 18, "fp_off": 6,
  "led_a": 70, "led_r": 45, "led_b": 1,
  "irr_h": 3, "irr_m": 15, "vent_h": 4, "vent_m": 20,
  "crop_start_day": 20693
}
```

`201` → `{ "config_id": 88, "applied_at": "2026-08-24T17:04:00-06:00" }`

Inserta una fila nueva en `device_configs`; **no** actualiza la anterior (es un histórico).
`led_b` es `0`/`1`: el LED blanco del firmware es ON/OFF, no PWM.

#### `POST /devices/{id}/telemetry`

Vía de arranque para la telemetría, y fallback puntual cuando MQTT esté en pie.

```json
{ "temp": 24.5, "humidity": 61.2, "wifi_rssi": -48, "uptime": 86400, "firmware_version": "1.0.1" }
```

`202` → `{ "accepted": 1 }`. Todos los campos son opcionales salvo que llegue al menos uno.
`ts` lo pone el servidor si no viene, para no depender del reloj del dispositivo.

#### `GET /firmware/latest?current=1.0.1`

`200` cuando hay actualización aplicable:

```json
{
  "version": "1.1.0",
  "url": "https://…/firmware/xyzver1.1.0.bin",
  "sha256": "<64 hex>",
  "signature": "<base64>",
  "size": 1002944
}
```

`204 No Content` cuando el dispositivo ya está al día. La `url` es prefirmada y temporal;
el binario se sirve **en streaming** desde el object storage, no a través del API.

### 4.2 App-facing (móvil/tablet → backend)

Autenticadas con **JWT de usuario** (`Authorization: Bearer <access>`).

#### `POST /auth/register` · `POST /auth/login`

```json
{ "email": "usuario@ejemplo.com", "password": "miClave123" }
```

`200` en ambos:

```json
{ "access_token": "<jwt>", "refresh_token": "<jwt>", "token_type": "bearer", "expires_in": 1800 }
```

`register` → `409` si el email ya existe. `login` → `401` si no coincide.

#### `POST /auth/refresh`

`{ "refresh_token": "<jwt>" }` → mismo sobre que login, con un `access_token` nuevo.

#### `GET /me/devices`

```json
{
  "devices": [
    { "id": 12, "mac": "A1:B2:C3:D4:E5:F6", "name": "Invernadero patio",
      "firmware_version": "1.0.1", "last_seen_at": "2026-08-24T16:58:00-06:00", "online": true }
  ]
}
```

`online` es derivado, no una columna: `last_seen_at` dentro de una ventana reciente.

#### `GET /devices/{id}/state`

Última configuración conocida más la lectura más reciente. `404` si el dispositivo no
pertenece a la cuenta autenticada — no `403`, para no revelar su existencia.

```json
{
  "device": { "id": 12, "name": "Invernadero patio", "online": true,
              "firmware_version": "1.0.1", "last_seen_at": "2026-08-24T16:58:00-06:00" },
  "config": { "planta": "Albahaca", "enable": true, "fp_on": 18, "fp_off": 6,
              "led_a": 70, "led_r": 45, "led_b": 1,
              "irr_h": 3, "irr_m": 15, "vent_h": 4, "vent_m": 20,
              "applied_at": "2026-08-24T17:04:00-06:00" },
  "crop": { "dia": 34, "semana": 5 },
  "telemetry": { "ts": "2026-08-24T16:58:00-06:00", "temp": 24.5,
                 "humidity": 61.2, "wifi_rssi": -48 }
}
```

`crop.dia` / `crop.semana` se **derivan** de `crop_start_day`, con la misma regla que el
firmware (ver §3 y *"Edad del cultivo"* en [`ARCHITECTURE.md`](ARCHITECTURE.md)). No se
almacenan.

#### `GET /devices/{id}/telemetry?from&to&bucket`

`from`/`to` en ISO 8601; `bucket` es el ancho de agregación (`5m`, `1h`, `1d`).

```json
{
  "device_id": 12, "bucket": "1h",
  "series": [
    { "ts": "2026-08-24T16:00:00-06:00", "temp_avg": 24.1, "temp_min": 23.4,
      "temp_max": 25.0, "humidity_avg": 60.8, "samples": 12 }
  ]
}
```

Se apoya en `time_bucket()` de Timescale, y en *continuous aggregates* cuando el rango lo
justifique. `400` si el rango es inválido o el `bucket` no está soportado.

### 4.3 Admin-facing (staff del fabricante → backend)

Autenticadas con **JWT de usuario con `is_admin = true`**. Ver §6.1 para el ciclo completo.

#### `POST /admin/firmware`

`multipart/form-data` con los campos `file` (el `.bin`), `version`, `min_version` y
`signature`. Sube el binario al object storage y registra el release.

`201`:

```json
{ "version": "1.1.0", "sha256": "<64 hex>", "size": 1002944,
  "published_at": "2026-08-24T17:10:00-06:00" }
```

`409` si la versión ya existe. El `sha256` lo calcula el servidor al recibir el archivo; no
se acepta del cliente.

#### `GET /admin/firmware`

```json
{
  "releases": [
    { "version": "1.1.0", "min_version": "1.0.0", "sha256": "<64 hex>",
      "published_at": "2026-08-24T17:10:00-06:00" }
  ]
}
```

---

## 5. Ingesta MQTT (telemetría)

- **Broker:** **Mosquitto**. Suficiente para una cuenta con pocos dispositivos; su
  configuración son 6 líneas. Migrar a EMQX más adelante cambia un servicio del compose,
  no la aplicación: el protocolo es el mismo.
- **Patrón:** el device mantiene **una** conexión MQTT/TLS persistente y publica
  telemetría a un tópico por dispositivo (p. ej. `devices/{id}/telemetry`).
- Un **consumidor** (servicio Python, puede vivir junto al API o aparte) se suscribe
  e inserta en la hypertable `device_telemetry`.
- **Por qué MQTT y no REST para esto:** el handshake TLS es lo caro en el C3; una
  conexión persistente lo amortiza. Detalle y trade-offs de TLS/memoria en el C3 →
  sección *"TLS en el ESP32-C3"* de [`ARCHITECTURE.md`](ARCHITECTURE.md).
- **Regla de oro del firmware:** *sin Wi-Fi → cero tráfico*; *sin token y sin acción
  del usuario → silencio total* (no hay polling de entitlement). Ver ARCHITECTURE.md.

### Caveat: Mosquitto no autentica contra la base de datos

Esta es la contrapartida de elegir Mosquitto y hay que resolverla antes de mover la
telemetría a MQTT. **EMQX trae autenticación contra BD de fábrica; Mosquitto no.**

El estado actual de `mosquitto/config/mosquitto.conf` es `allow_anonymous true`: cualquiera
en la red puede publicar y suscribirse. Sirve para desarrollo local, **no** para nada
expuesto.

Tres caminos, en orden de esfuerzo creciente:

| Opción | Cómo funciona | Cuándo conviene |
|---|---|---|
| **REST primero** | La telemetría entra por `POST /devices/{id}/telemetry` con el token de dispositivo. MQTT se suma después. | Arranque. Desbloquea el resto del backend sin resolver esto ya. |
| **Archivo de contraseñas** | El backend regenera el archivo de Mosquitto (`mosquitto_passwd`) al provisionar y recarga el broker. Usuario = `device_id`, contraseña = token. | Pocos dispositivos, despliegue propio. |
| **Plugin contra Postgres** | `mosquitto-go-auth` valida usuario/contraseña y ACLs por tópico consultando `devices.token_hash`. | Cuando haya varios dispositivos o se exponga el broker. |

Recomendación: **arrancar por REST** y añadir MQTT cuando el resto esté en pie. El modelo
de datos no cambia — `device_telemetry` recibe lo mismo por cualquiera de las dos vías.

---

## 6. OTA — publicación, notificación y descarga

El ciclo completo del firmware over-the-air. Tres piezas ya diseñadas lo sostienen y
**ninguna tabla nueva hace falta**: `firmware_releases` (catálogo de versiones),
el **object storage** (guarda el `.bin`) y `devices.firmware_version` (versión vigente
de cada equipo).

### 6.1 Publicación de un release (admin)

Actor nuevo: **admin** = staff del fabricante, distinto de los usuarios finales. Se
modela con el flag `is_admin` en `users` (§3); las rutas `/admin/*` lo exigen.

Flujo recomendado — **subida a través del backend** (los binarios del C3 son pequeños,
~1–2 MB, así que no vale la pena complicarlo):

1. `POST /admin/firmware` (multipart): `.bin` + `version` + `min_version` + `signature`.
   Requiere JWT con `is_admin`.
2. El backend **sube el binario al object storage** en streaming (no lo carga entero en
   RAM), a una ruta determinista, p. ej. `firmware/{version}.bin`.
3. El backend **calcula el `sha256` del lado del servidor** leyendo el objeto ya
   guardado — **no** confía en un hash provisto por el cliente. Garantiza que `url` y
   `sha256` sean consistentes.
4. Inserta la fila en `firmware_releases` (`version`, `url`, `sha256`, `signature`,
   `min_version`, `published_at`).

**Alternativa (binarios grandes / descargar carga del API): presigned URL.** El backend
devuelve una URL de subida firmada, el admin sube **directo** al object storage y luego
confirma con `POST /admin/firmware/confirm` para registrar los metadatos. Para el C3 no
hace falta; se documenta por si el sistema crece.

**Inmutabilidad:** `version` es PK → re-publicar la misma versión **falla a propósito**.
Un release no se sobrescribe; si hubo un error, se publica una versión nueva. Así ningún
equipo queda con un `sha256` que ya no cuadra con el binario.

**Firma (OTA segura):** la firma se genera **offline, con una clave privada que NO vive
en el servidor**; el device la verifica con la clave pública embebida en su flash. Poner
la clave de firma en el backend anularía la protección si el servidor se compromete. Por
eso el admin **provee** la `signature` ya calculada al publicar (paso 1); el backend no
firma, solo la almacena.

### 6.2 Notificación de disponibilidad

Dos mecanismos **complementarios** (no alternativos): un push rápido + un poll de red de
seguridad.

- **Push por el canal de telemetría (rápido).** Al publicar un release, el backend
  publica en un tópico de bajada MQTT (`devices/{id}/ota` o uno común) con la versión
  disponible. **Mensaje retenido (`retain=true`)** para que un device que estaba offline
  lo reciba al reconectar y suscribirse. *(Si la telemetría fuera REST en vez de MQTT, el
  aviso viaja en el **body JSON** de la respuesta de telemetría — no en headers, que MQTT
  no tiene.)*
- **Poll diario (red de seguridad).** Una vez al día el device hace
  `GET /firmware/latest?current=X`. Garantiza que se ponga al día **aunque perdiera el
  push** (mensaje no retenido, reinicio inoportuno, bug). Costo ínfimo: un request
  minúsculo al día.

> El push sin el poll es frágil (si se pierde el aviso, el equipo queda desactualizado);
> el poll sin el push funciona pero con hasta 24 h de retraso. **Juntos: rápido y
> robusto.** El backend decide "hay update" comparando `current` (o
> `devices.firmware_version`) contra `firmware_releases` (última versión con
> `min_version <= current`).

### 6.3 Descarga y verificación (device)

Al detectar update por cualquiera de los dos canales:

1. `GET /firmware/latest?current=X` → metadatos (`url`, `sha256`, `signature`).
2. Descarga el `.bin` **en streaming** desde el object storage (`httpUpdate.update()`; no
   cabe entero en RAM).
3. **Verifica `sha256`** (integridad) y **`signature`** con la clave pública embebida
   (autenticidad). Si algo no cuadra, aborta sin escribir.
4. Escribe la partición OTA y reinicia en la versión nueva; el siguiente contacto reporta
   el nuevo `firmware_version` (que a su vez apaga el aviso).

Detalle de TLS/streaming y CA pinning en el C3 → sección *"OTA sobre TLS"* de
[`ARCHITECTURE.md`](ARCHITECTURE.md).

---

## 7. Portabilidad servidor propio ↔ nube

El destino es **servidor propio hoy, cloud-ready mañana**. No cambia el stack; impone
disciplina. Cuatro reglas:

1. **Config 100% por variables de entorno (12-factor).** Nada de endpoints,
   credenciales ni hosts hardcodeados. `.env` distinto por entorno; código igual.
   *Es la regla que más portabilidad compra.*
2. **Todo en Docker.** Corre idéntico en compose (servidor) y en la nube
   (ECS/EKS/Cloud Run/VM).
3. **Interfaces estándar, sin lock-in.** Storage S3-compatible (MinIO ↔ S3 con solo
   cambiar `endpoint_url`); **MQTT plano** (evitar features propietarias tipo AWS IoT
   Core si se quiere poder migrar el broker); Postgres + extensión Timescale estándar.
4. **TLS desacoplado del app.** En servidor lo pone Caddy/Traefik; en nube, un load
   balancer gestionado. FastAPI nunca termina TLS → da igual dónde corra.

### ⚠️ Gotcha crítico: TimescaleDB + nube gestionada
**AWS RDS gestionado NO soporta la extensión TimescaleDB** (GCP/Azure gestionados,
tampoco). Si se migra a base de datos *gestionada*, las opciones son:
- **Timescale Cloud** (managed, la vía limpia), o
- Postgres self-managed en una VM/EC2 (tú corres el contenedor), o
- renunciar a Timescale y usar **particionado nativo de Postgres**.

En servidor propio no hay problema (corre en Docker). Tenerlo presente **antes** de
migrar para no llevarse la sorpresa.

---

## 8. Cómo arrancar

**Estado:** diseño cerrado y sin ambigüedades. Nada queda por decidir.

Lo que **ya está resuelto** y no hay que rehacer:

- El **DDL** del §3, en [`../pythonServer/db/schema.sql`](../pythonServer/db/schema.sql):
  tablas, FKs con `ON DELETE CASCADE`, la extensión, `create_hypertable()` y los índices
  `(device_id, ts DESC)` y `(device_id, applied_at DESC)`. Es la base de la migración inicial.
- Los **contratos de la API** con payloads exactos (§4).
- El **`docker-compose.yml`**: `docker compose up -d` levanta Postgres/Timescale (5432),
  MinIO (9000/9001) y Mosquitto (1883) sin conflictos.

### El esquema lo administra Alembic

Decisión importante para no tener dos dueños del esquema: el compose **ya no** aplica
`schema.sql`. Levanta un Postgres vacío con Timescale disponible, y **Alembic** crea todo.

Alembic mantiene una secuencia versionada de scripts con `upgrade()`/`downgrade()`, y anota
en la tabla `alembic_version` qué revisión está aplicada. Así, `alembic upgrade head` lleva
cualquier entorno —tu máquina, la Raspberry Pi, producción— al mismo esquema de forma
determinista, sin destruir el volumen ni aplicar SQL a mano.

Dos cosas que Alembic **no** hace solo con Timescale y hay que escribir a mano:

```python
def upgrade():
    op.execute("CREATE EXTENSION IF NOT EXISTS timescaledb")
    # ... create_table de users, devices, device_configs, device_telemetry, firmware_releases
    op.execute("SELECT create_hypertable('device_telemetry', 'ts')")
```

`revision --autogenerate` no detecta la extensión ni la hypertable, y `device_telemetry`
necesita la PK compuesta `(id, ts)` porque Timescale exige que la columna de partición
forme parte de la clave.

### Orden de entregables

1. **Migración inicial de Alembic** que reproduzca `schema.sql`, con extensión e hypertable.
2. **Esqueleto FastAPI**: estructura del proyecto, `settings` por variables de entorno
   (§7), modelos SQLAlchemy y `get_db()` async.
3. **Auth de usuario** (§4.2): `register` / `login` / `refresh` con JWT y hash bcrypt.
4. **Provisión de dispositivos** (§4.0, §4.1): `/devices/provision` emite el token y
   persiste solo `token_hash`; dependencia de FastAPI que resuelve `Bearer` → dispositivo.
5. **Config y telemetría por REST** (§4.1): `/devices/{id}/config` y
   `/devices/{id}/telemetry`. Con esto el ciclo dispositivo↔nube ya cierra.
6. **Lecturas para la app** (§4.2): `/me/devices`, `/state` y el histórico con `time_bucket`.
7. **OTA** (§6): `/admin/firmware` sube a MinIO y registra el release; `/firmware/latest`
   resuelve aplicabilidad y devuelve URL prefirmada.
8. **MQTT** (§5): resolver primero la autenticación del broker (ver el caveat), luego el
   consumidor suscrito a `devices/+/telemetry`.
9. **TLS** con Caddy y el servicio `backend` del compose habilitados.

### Checklist de arranque

- [x] `docker compose up -d` levanta Postgres/Timescale, MinIO y Mosquitto sin conflictos.
- [x] Migración inicial de Alembic crea el esquema del §3 (extensión + tablas + hypertable).
- [x] Endpoints de auth (`register`/`login`/`refresh`) emiten y validan JWT.
- [x] `/devices/provision` emite token de dispositivo y persiste `token_hash`.
- [x] `/devices/{id}/config` y `/devices/{id}/telemetry` autenticados por `Bearer`. **Verificado en ejecución** (config inserta histórico, telemetría fija `ts` en servidor y refresca `last_seen_at`/`firmware_version`, y los casos negativos 401/400 responden). Se requirió un fix: `Settings` en `app/settings.py` ahora usa `extra = "ignore"` porque el `.env` es compartido con Postgres/MinIO y pydantic v2 abortaba el arranque.
- [x] `/me/devices` y `/devices/{id}/state` responden con el aislamiento por cuenta del §4.2. **Verificado en ejecución**; incluye también `GET /devices/{id}/telemetry` (histórico con `time_bucket`). Fix: `time_bucket` recibe el ancho como `timedelta` (asyncpg lo mapea a `interval`); pasarlo como string devuelve `500`.
- [ ] `POST /admin/firmware` (JWT admin) sube el binario al object storage y registra el release.
- [ ] `/firmware/latest` devuelve metadatos y el binario se sirve desde MinIO/S3.
- [ ] Autenticación del broker resuelta y consumidor MQTT insertando en la hypertable.
- [ ] Push OTA por MQTT retenido + poll diario notifican al device (§6.2).
- [ ] Caddy termina TLS y el servicio `backend` corre en el compose.

### Estado de verificación

Qué está probado contra el stack real y qué no, para no dar por bueno lo que no se ejecutó.

| Entregable | Código | Verificado en ejecución |
|---|---|---|
| Infra (Postgres/Timescale, MinIO, Mosquitto) | ✅ | ✅ `docker compose up -d` sin conflictos |
| Migración `001` (extensión + 5 tablas + hypertable) | ✅ | ✅ `alembic current` → `001 (head)`, 6 tablas presentes |
| Auth de usuario (`register`/`login`/`refresh`) | ✅ | ✅ `201`/`200` y JWT emitido |
| `POST /devices/provision` | ✅ | ✅ alta `201`, re-provisión rota el token, `401` con password malo, `409` si la MAC es de otra cuenta, y en BD solo queda `token_hash` (`$2b$12$…`, 60 chars) |
| `POST /devices/{id}/config` | ✅ | ✅ `201` `{config_id, applied_at}`; una segunda llamada **inserta otra fila** (histórico, ids 1 y 2), no actualiza |
| `POST /devices/{id}/telemetry` | ✅ | ✅ `202` `{accepted:1}`; `ts` lo pone el servidor y `devices.last_seen_at`/`firmware_version` se refrescan; body vacío `{}` → `400` |
| Dependencia `get_current_device` (Bearer) | ✅ | ✅ sin `Authorization` → `401`; token inválido/ajeno o id inexistente → `401` (sin revelar el id) |
| Dependencia `get_current_user` (JWT de usuario) | ✅ | ✅ sin token → `401`; **refresh** token → `401` (solo `type=access`) |
| `GET /me/devices` | ✅ | ✅ `200`; `online` derivado de `last_seen_at`; solo devuelve los del dueño (Bob ve lista vacía) |
| `GET /devices/{id}/state` | ✅ | ✅ `200` con última config + telemetría; `crop.dia/semana` derivados de `crop_start_day` (33 días → día 34, semana 5); `404` si el device es de otra cuenta o no existe |
| `GET /devices/{id}/telemetry?from&to&bucket` | ✅ | ✅ agregación con `time_bucket` (`1h`→3 buckets, `1d`→1 bucket/5 samples); `400` bucket no soportado o `from>to`; `404` si no es del dueño |

**Nota de entorno.** El puerto **5432 del host puede estar ocupado** por otra instancia de
Postgres; para levantar este stack en ese caso hay que remapear puertos con un override
(`ports: !override` — en Compose las listas de `ports` se **concatenan**, no se reemplazan,
sin esa directiva).

---

## 9. Referencias cruzadas
- [`ARCHITECTURE.md`](ARCHITECTURE.md) — diseño del firmware; secciones *"Modelado de
  la base de datos (backend futuro)"* y *"TLS en el ESP32-C3"* son el origen de este doc.
- [`API.md`](API.md) — API HTTP del firmware
  (llaves de `/newparams` que `device_configs` debe espejar).
- `README.md` — roadmap del proyecto (el ítem *"Backend (FastAPI + Postgres)"* lo
  desarrolla este documento).

---

## 10. Guía de Despliegue en Raspberry Pi (Pruebas y Producción)

Para correr el proyecto en una Raspberry Pi y garantizar que la configuración sirva en entornos de producción más profesionales sin necesidad de reescribir nada, se ha provisto el archivo `docker-compose.yml` base bajo el enfoque de **Infraestructura como Código (IaC)**.

### Prerrequisitos de Hardware
1. **Sistema Operativo 64-bit:** Es **obligatorio** usar Raspberry Pi OS de 64 bits para tener soporte nativo con las imágenes oficiales de TimescaleDB y MinIO en arquitectura ARM64.
2. **SSD Externo (Crítico):** **NO utilices una tarjeta MicroSD** para almacenar la base de datos de telemetría. Las escrituras constantes por MQTT corromperán la tarjeta rápidamente. Usa un disco SSD conectado por USB y asegúrate de que los volúmenes de Docker se alojen en este almacenamiento.
3. **RAM:** Se recomienda encarecidamente una Raspberry Pi 4 o 5 de al menos 4 GB de RAM.

### Despliegue
1. Dirígete a la carpeta `pythonServer/`.
2. Copia el archivo `.env.example` a `.env` y configura tus secretos (especialmente contraseñas de BD y MinIO). **Nunca subas este archivo al repositorio**.
3. Revisa la configuración base del broker en `pythonServer/mosquitto/config/mosquitto.conf`.
4. Ejecuta: `docker-compose up -d`.

### De Pruebas a Producción
La gran ventaja de este diseño "Cloud-Ready" es que cuando desees llevar este backend a un entorno en la nube público (AWS, DigitalOcean, GCP):
- Solo deberás copiar el archivo `docker-compose.yml` y tu `.env` (con claves de producción seguras).
- Ajustarás `Caddy` para proveer los certificados de Let's Encrypt para tu dominio de producción.
- **Tu código y arquitectura no sufrirán modificaciones.**

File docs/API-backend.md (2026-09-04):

# API HTTP del backend (nube)

Rutas que expone el servicio **FastAPI** de la nube (`pythonServer/`). Es la API que consumen dos clientes muy distintos: el **dispositivo** (ESP32-C3, tras provisionarse) y la **app** del usuario (móvil/tablet). No confundir con la [API local del dispositivo](API.md), que es un contrato aparte servido por el propio firmware en la red del AP.

**Fuente:** `pythonServer/app/main.py`, `app/routers/auth.py`, `app/routers/devices.py`, `app/routers/me.py`, `app/deps.py`, `app/security.py`, `app/models.py`.

> El **diseño autoritativo** (modelo de datos, decisiones y contratos completos, incluyendo lo aún no implementado) está en [`BACKEND.md`](BACKEND.md). Este documento describe lo que **existe en el código** y marca explícitamente lo que todavía **no** está implementado.

---

## Estado de implementación

| Superficie | Rutas | Estado |
|---|---|---|
| Salud | `GET /health` | ✅ Implementado y verificado |
| Auth de usuario | `POST /auth/register` · `/login` · `/refresh` | ✅ Implementado y verificado |
| Provisión de dispositivo | `POST /devices/provision` | ✅ Implementado y verificado |
| Device-facing | `POST /devices/{id}/config` · `/telemetry` | ✅ Implementado y verificado |
| App-facing | `GET /me/devices` · `/devices/{id}/state` · `/devices/{id}/telemetry` | ✅ Implementado y verificado |
| OTA (device) | `GET /firmware/latest` | ⛔ No implementado — diseño en [`BACKEND.md` §4.1/§6](BACKEND.md) |
| Admin (firmware) | `POST /admin/firmware` · `GET /admin/firmware` | ⛔ No implementado — diseño en [`BACKEND.md` §4.3/§6](BACKEND.md) |
| Ingesta MQTT | `devices/+/telemetry` | ⛔ No implementado — diseño en [`BACKEND.md` §5](BACKEND.md) |

---

## Convenciones

- Todo es JSON con `Content-Type: application/json` (la subida de firmware, cuando exista, será `multipart/form-data`).
- Los **errores** usan el formato de FastAPI: `{"detail": "<mensaje>"}` con el código HTTP correspondiente. No hay sobre `{status, message}` como en la API del dispositivo.
- Los **timestamps** son ISO 8601 con zona (`2026-09-03T21:44:08+00:00`). Los pone el servidor.
- `{id}` en las rutas es `devices.id` (entero autoincremental), **no** la MAC.
- Códigos habituales: `200`/`201`/`202` éxito · `400` validación de negocio · `401` autenticación · `404` recurso ajeno o inexistente · `409` conflicto · `422` body mal formado (validación de Pydantic).
- La documentación OpenAPI viva está en `/docs` (Swagger UI) y `/openapi.json`.

---

## Autenticación

El backend maneja **dos esquemas de credenciales distintos**, ambos vía cabecera `Authorization: Bearer <…>`. No se cruzan: un token de dispositivo no sirve en rutas de la app, y viceversa.

| | JWT de usuario | Token de dispositivo |
|---|---|---|
| Lo usa | La app (móvil/tablet) | El ESP32 tras provisionarse |
| Formato | JWT firmado (HS256) | 64 caracteres hex (`secrets.token_hex(32)`) |
| Se emite en | `register` / `login` / `refresh` | `POST /devices/provision` (una sola vez) |
| Se guarda en BD | Solo el hash de la contraseña (`users.password_hash`) | Solo `devices.token_hash` (bcrypt) |
| Dependencia | `get_current_user` (`app/deps.py`) | `get_current_device` (`app/deps.py`) |
| Vigencia | `access` 30 min · `refresh` 7 días | Hasta que se revoque (borrar/rotar la fila) |
| Rutas | `/me/*`, `GET /devices/{id}/state`, `GET /devices/{id}/telemetry` | `POST /devices/{id}/config`, `POST /devices/{id}/telemetry` |

> **No confundir** el token de dispositivo del backend con el **token de sesión del portal local** del firmware (RAM, 30 min, red del AP). Son cosas distintas; la comparación está en el [§4.0 de `BACKEND.md`](BACKEND.md).

### JWT de usuario (`get_current_user`)

El JWT lleva `sub` (id del usuario), `admin` (bool) y `type` (`access` o `refresh`). La dependencia:

1. Exige la cabecera `Authorization: Bearer <jwt>` → si falta, `401`.
2. Valida firma y expiración con `JWT_SECRET_KEY` / `JWT_ALGORITHM` → si falla, `401`.
3. Exige `type == "access"`: un **refresh token no autentica** peticiones normales → `401`.
4. Resuelve `sub` a `users.id`; si el usuario no existe, `401`.

Todos los fallos responden `401` con `{"detail": "<causa>"}` y `WWW-Authenticate: Bearer`.

### Token de dispositivo (`get_current_device`)

En rutas `POST /devices/{device_id}/...`. La dependencia trae el dispositivo por su `{device_id}` y verifica el token con `verify_secret(token, device.token_hash)` (bcrypt). No se puede buscar por `WHERE token_hash = hash(token)` porque bcrypt usa un salt distinto en cada hash.

Si el dispositivo no existe **o** el token no verifica, responde el **mismo** `401`: no se revela la existencia de un id a quien no trae el token correcto.

### Aislamiento por cuenta (rutas de la app)

`GET /devices/{id}/state` y `GET /devices/{id}/telemetry` filtran por `Device.user_id == user.id` en el `WHERE`. Si el id existe pero pertenece a **otra** cuenta, la consulta sale vacía y se responde `404` (no `403`), para no revelar su existencia.

---

## `GET /health`

Health check. Sin autenticación.

| | |
|---|---|
| Handler | `main.health` |
| Entrada | — |
| Respuesta | `{ "status": "ok" }` |

---
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

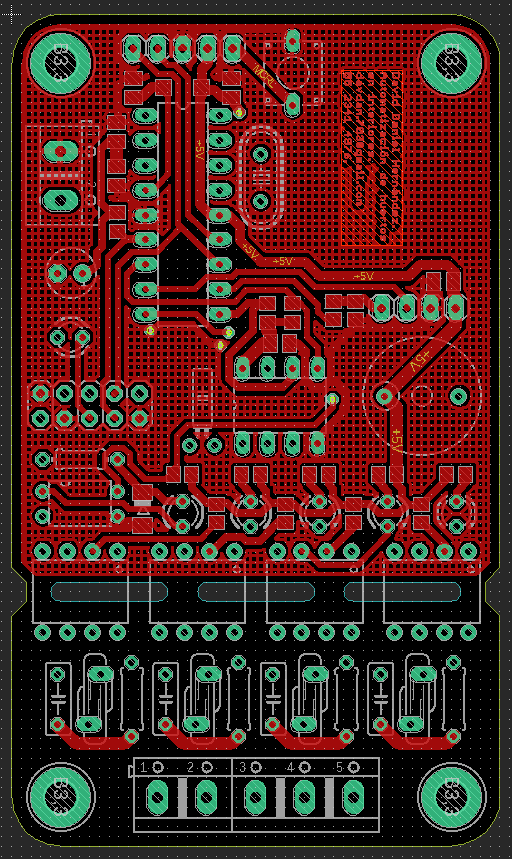
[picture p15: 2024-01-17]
docs/img/picTop.png

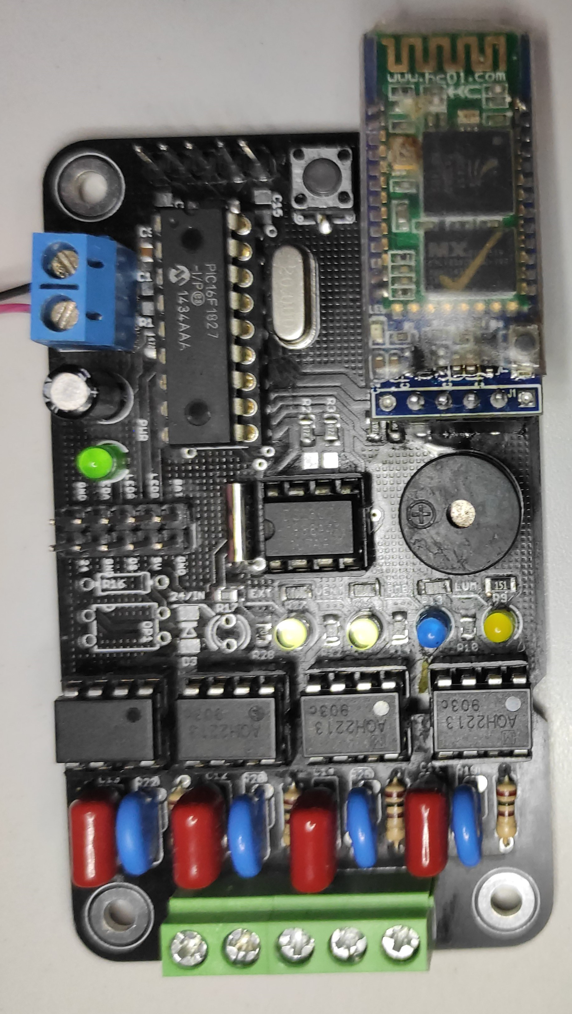
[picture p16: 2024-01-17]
docs/img/picBoard.jpg

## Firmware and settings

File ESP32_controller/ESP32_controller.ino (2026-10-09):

#include <Arduino.h>
#include <WiFi.h>
#include <DNSServer.h>
#include <WebServer.h>
#include <Update.h>
#include "Constants.h"
#include "sensible.h"
#include "Plant.h"
#include "mainForm.h" 

DNSServer dnsServer;
// Ligado a la IP del SoftAP, NO al wildcard: el portal es el plano de control
// LOCAL y no debe responder por la interfaz STA. Con `WebServer server(80)` el
// socket se ligaba a 0.0.0.0 y, en cuanto el equipo se unía a la red del usuario,
// todos los endpoints quedaban accesibles desde esa LAN sin conocer la passphrase
// del AP. El constructor solo guarda la dirección; el bind() real ocurre en
// server.begin(), que corre cuando el AP ya está levantado.
WebServer server(apGatewayIp, 80);

Plant planta;

HttpResponse response;

// index page handler
void handleRoot();
void handleNotFound();
void handleUserCredentials();
void handleGetParameters();
void handleNewParameters();
void handleNewCrop();
void handleAuthUserCredentials();
void handleExit();
void handleWifiScan();
void handleWifiCredentials();
void handleOtaUpdate();
void handleOtaUpload();

void setup() {
  
  planta.begin();

  // ===== Configuración de red (AP puro o AP+STA), toda aquí =====
  // Una sola radio en el ESP32-C3: el AP y el STA comparten canal. Fijamos el
  // modo dual EXPLÍCITO para que WiFi.begin() del STA no reconfigure el modo por
  // debajo, y creamos el SoftAP antes de arrancarlo.
  WiFi.mode(WIFI_AP_STA);

  // AP con WPA2-PSK (passphrase en sensible.h): cifra el enlace para que las
  // credenciales del usuario y el token de sesión no viajen en claro. create()
  // selecciona WPA2 automáticamente al recibir una passphrase de >= 8 caracteres.
  WiFi.AP.create(apSsid, apPassword);
  WiFi.AP.begin();
  WiFi.AP.enableDhcpCaptivePortal();

  // El WebServer se liga a apGatewayIp (ver Constants.h). Si el SoftAP no acabara
  // en esa IP, el bind fallaría en silencio y el portal quedaría inaccesible sin
  // ningún error visible, así que se comprueba y se avisa aquí.
  if (WiFi.softAPIP() != apGatewayIp) {
    Serial.printf("[AP] AVISO: el SoftAP tiene %s pero el servidor se liga a %s. "
                  "El portal NO responderá: ajusta apGatewayIp en Constants.h.\n",
                  WiFi.softAPIP().toString().c_str(), apGatewayIp.toString().c_str());
  } else {
    Serial.printf("[AP] Portal servido solo en %s (la interfaz STA no lo expone)\n",
                  apGatewayIp.toString().c_str());
  }

  // Desactiva el modem-sleep: con STA habilitado el ESP32 duerme la radio según
  // el ciclo del STA (WIFI_PS_MIN_MODEM por defecto), lo que deja al SoftAP sin
  // responder y el portal no carga. Sin sleep el AP responde estable en AP+STA.
  WiFi.setSleep(false);

  // Conexión a la red del usuario (STA) SOLO si ya hay credenciales guardadas:
  // el AP queda siempre arriba y, con credenciales, el dispositivo pasa a AP+STA.
  // Sin ellas se queda como AP puro (caso "básico"/sin configurar). No bloquea:
  // setAutoReconnect mantiene el enlace tras cortes y el loop observa el intento.
  if (planta.getWifiCredentials() && strlen(planta.getSsid()) > 0) {
    WiFi.setAutoReconnect(true);
    WiFi.begin(planta.getSsid(), planta.getWifiPass());
    Serial.printf("[WIFI] Conectando a %s…\n", planta.getSsid());
  }

  // by default DNSServer is started serving any "*" domain name. It will reply
  // AccessPoint's IP to all DNS request (this is required for Captive Portal detection)
  if (dnsServer.start()) {
    Serial.println("[System] Portal captivo iniciado");
  } else {
    Serial.println("[System] No se puede iniciar portal captivo");
  }

  // serve a simple root page
  server.on("/", handleRoot);
  server.on("/usercredentials", HTTP_POST, handleUserCredentials);
  server.on("/getparams", HTTP_GET, handleGetParameters);
  server.on("/newparams", HTTP_POST, handleNewParameters);
  server.on("/newcrop", HTTP_POST, handleNewCrop);
  server.on("/authusercredentials", HTTP_POST, handleAuthUserCredentials);
  server.on("/wifiscan", HTTP_GET, handleWifiScan);
  server.on("/wificredentials", HTTP_POST, handleWifiCredentials);
  // OTA local: subida del .bin por multipart. Dos callbacks: el segundo recibe el
  // archivo por trozos (handleOtaUpload) y el primero responde al terminar
  // (handleOtaUpdate). El token va en el header Authorization: Bearer (el cuerpo
  // es multipart), y por eso hay que registrar esa cabecera con collectHeaders()
  // para que WebServer la conserve.
  const char* otaHeaders[] = { "Authorization" };
  server.collectHeaders(otaHeaders, 1);
  server.on("/otaupdate", HTTP_POST, handleOtaUpdate, handleOtaUpload);
  server.on("/exit", handleExit);
  server.onNotFound(handleNotFound);
  server.begin();

  // Lectura puntual del RTC para que el pitido de arranque refleje el estado real
  // del reloj. (El punto de I²C PERIÓDICO sigue siendo el loop; esto es una sola
  // lectura de inicialización.)
  planta.getCurrentTime();

  // Sistema listo: 1 pitido de confirmación de arranque (y prueba del buzzer en
  // cada encendido). No bloqueante: lo reproduce buzzerUpdate() desde loop().
  // Si el RTC NO dio hora fiable, suena en cambio el patrón de advertencia
  // (buzzerBeepsRtcFail): el equipo no accionará nada hasta sincronizar la hora.
  planta.buzzerBeep(planta.isRtcValid() ? buzzerBeepsBoot : buzzerBeepsRtcFail);

}

void loop() {
  // handleClient() corre en cada iteración (sin delay bloqueante) para que el
  // portal responda al instante. El control de dispositivos no necesita esa
  // frecuencia: se throttlea con millis() a deviceUpdateInterval. 
  server.handleClient();

  // Reproductor de pitidos del buzzer: no bloquea, avanza con millis(). Debe ir
  // junto a handleClient() (cada iteración) para que los tiempos sean precisos.
  planta.buzzerUpdate();

  static uint32_t lastDeviceUpdate = 0;
  uint32_t now = millis();
  if (now - lastDeviceUpdate >= deviceUpdateInterval) {
    lastDeviceUpdate = now;
    // Único punto de I²C periódico: refresca _currentTime desde el RTC.
    planta.getCurrentTime();
    planta.turnOnDevices();
    // Persiste las credenciales Wi-Fi si un intento pendiente acaba de conectar.
    planta.updateWifi();
  }

  // El log del estado se imprime AQUÍ, no en una tarea aparte. Antes lo hacía un
  // printTask que leía _currentTime/_systemStatus mientras este loop los
  // reescribía: sin sincronización, podía imprimir un arreglo a medio actualizar
  // (p. ej. una hora mezclada). Con un solo task tocando ese estado la carrera
  // desaparece por construcción, sin necesidad de mutex, y se ahorran los 2 KB de
  // stack de la tarea.
  static uint32_t lastLog = 0;
  if (now - lastLog >= systemLogInterval) {
    lastLog = now;
    planta.printSystemData();
    //Serial.printf("Stack libre minimo (loop): %u bytes\n", uxTaskGetStackHighWaterMark(NULL));
  }

  delay(2);  // cede CPU al IDLE task (alimenta el watchdog) sin la latencia del delay(250) previo
}

void handleRoot() {
  // Página estática única. El cliente pide /getparams y, según hasRegisteredUser,
  // pinta la bienvenida o el dashboard.
  // El portal va COMPRIMIDO con gzip (mainForm_gz, generado por gen_mainform.py):
  // ~12–18 KB en vez de ~73 KB -> menos flash, menos chunks por el AP y carga más
  // rápida. Se declara Content-Encoding: gzip y el navegador lo descomprime solo.
  // send_P sirve directo desde flash (sin String temporal); al ser binario (tiene
  // bytes nulos) se pasa la LONGITUD explícita.
  server.sendHeader("Content-Encoding", "gzip");
  server.send_P(200, "text/html", (const char*)mainForm_gz, mainForm_gz_len);
  Serial.println("*****  " + server.uri() + "  *****");
}

void handleNotFound() {
  server.sendHeader("Location", "/");
  server.send(302, "text/plain", "redirect to captive portal");
}

void handleUserCredentials() {

  String body = server.arg("plain");
  Serial.println("*****  " + server.uri() + "  *****");
  if (server.args() > 0) 
    for (int i = 0; i < server.args(); i++) 
      Serial.printf("%s = %s\n", server.argName(i).c_str(), server.arg(i).c_str());

  requestStatus status = planta.validateUserCredentials(body);

  // Registro OK → el usuario nuevo queda autenticado: emitimos un token de
  // sesión y lo devolvemos para que entre a editar 30 min sin re-loguearse. El
  // usuario ya quedó en RAM/Preferences; no se reinicia.
  if (status == STATUS_OK) {
    String token = planta.issueSessionToken();
    server.send(200, "application/json",
                "{\"status\":true,\"message\":\"Usuario registrado.\",\"token\":\"" + token + "\"}");
    return;
  }

  response = buildHttpResponse(status);
  server.send(response.code, response.contentType, response.body);
}

void handleGetParameters() {
  // Devuelve el estado del dispositivo en JSON (incluye hasRegisteredUser y, si
  // se manda ?token=, sessionValid). El token viene en la query porque /getparams
  // es GET; buildParamsJson lo valida para reportar sessionValid, pero NO renueva
  // la sesión: la ventana es FIJA desde el login.
  server.send(200, "application/json", planta.buildParamsJson(server.arg("token")));
  Serial.println("*****  " + server.uri() + "  *****");
}

void handleAuthUserCredentials() {
  String body = server.arg("plain");
  Serial.println("*****  " + server.uri() + "  *****");

  // ¿La petición entró por la interfaz del AP? localIP() es la IP LOCAL del socket,
  // es decir la interfaz que aceptó la conexión: por el AP vale softAPIP(), por el
  // STA la IP de la red del usuario. No es un dato que el cliente envíe, así que no
  // se puede falsificar como una cabecera. Solo se usa para autorizar el comando de
  // reset (ver Plant::authUserCredentials). Fail-closed: si no hay IP de AP válida
  // se deniega, en lugar de permitir.
  IPAddress apIp = WiFi.softAPIP();
  bool fromAP = (apIp != IPAddress((uint32_t)0)) && (server.client().localIP() == apIp);

  requestStatus status = planta.authUserCredentials(body, fromAP);

  // Login OK → emitimos token de sesión y lo devolvemos para desbloquear la
  // edición durante 30 min sin re-autenticar en cada carga.
  if (status == STATUS_OK) {
    String token = planta.issueSessionToken();
    server.send(200, "application/json",
                "{\"status\":true,\"message\":\"Acceso concedido.\",\"token\":\"" + token + "\"}");
    return;
  }

  response = buildHttpResponse(status);

  // Valida para desbloquear la edición sin reiniciar, EXCEPTO cuando se recibe
  // el comando de reset (**reset**): ahí hardReset() ya corrió y reiniciamos.
  server.send(response.code, response.contentType, response.body);
  if (status == HARD_RESET) {
      Serial.println("[System] Hard reset");
      // Reset de fábrica: 1 pitido largo SÍNCRONO (como OTA OK), porque el equipo
      // reinicia de inmediato y el reproductor del loop no alcanzaría a sonar.
      digitalWrite(buzzerPin, deviceOn);
      delay(600);
      digitalWrite(buzzerPin, deviceOff);
      vTaskDelay(pdMS_TO_TICKS(400));
      ESP.restart();
  } else if (status == MISMATCH_CREDENTIALS || status == TOO_MANY_ATTEMPTS) {
      // Login fallido o bloqueado: patrón de error no bloqueante, distinto de la
      // confirmación, para que un error no se confunda con un éxito.
      planta.buzzerBeep(buzzerBeepsError);
  }
}

void handleNewParameters() {
  String body = server.arg("plain");
  Serial.println("*****  " + server.uri() + "  *****");
  if (server.args() > 0) 
    for (int i = 0; i < server.args(); i++) 
      Serial.printf("%s = %s\n", server.argName(i).c_str(), server.arg(i).c_str());

  requestStatus status = planta.validateCropParameters(body);
  response = buildHttpResponse(status);

  server.send(response.code, response.contentType, response.body);

  // Confirmación sonora de "parámetros aplicados": 3 pitidos no bloqueantes.
  // Se dispara tras responder, solo si la validación fue correcta.
  if (status == STATUS_OK) planta.buzzerBeep(buzzerBeepsParams);

}

void handleNewCrop() {
  // Cierra el cultivo actual: borra nombre, ancla de días y parámetros, y conserva
  // la cuenta y la Wi-Fi. Exige token de sesión (es una acción destructiva del
  // dueño, no una vía de recuperación). El reset de FÁBRICA es otra cosa: vive en
  // /authusercredentials como el comando **reset**, sin token y solo por el AP.
  String body = server.arg("plain");
  Serial.println("*****  " + server.uri() + "  *****");

  requestStatus status = planta.startNewCrop(body);
  response = buildHttpResponse(status);
  server.send(response.code, response.contentType, response.body);
}

void handleExit() {
  // Logout: invalida la sesión de edición en el dispositivo (el front además
  // limpia su token en localStorage). Responde JSON {status, message} que el
  // front pinta en la pantalla de cierre.
  planta.clearSession();
  server.send(200, "application/json", "{\"status\":true,\"message\":\"Desconectado correctamente. Ya puedes cerrar esta ventana y desconectarte de la red SmartPlant.\"}");
  Serial.println("*****  " + server.uri() + "  *****");
}

void handleWifiScan() {
  // Escaneo on-demand: el dispositivo busca redes y devuelve las 5 más fuertes
  // sin nombres repetidos. No usa el sobre {status,message}: entrega la lista
  // directa (igual que /getparams). Asíncrono: arranca el escaneo y responde
  // scanning=true; el front consulta hasta recibir la lista.
  server.send(200, "application/json", planta.scanNetworks());
  Serial.println("*****  " + server.uri() + "  *****");
}

void handleWifiCredentials() {
  // Recibe {ssid, pass, token}, valida y ARRANCA la conexión (sin bloquear). El
  // front confirma el resultado por polling a /getparams (wifiConnected). Exige
  // token de sesión vigente, igual que /newparams.
  String body = server.arg("plain");
  Serial.println("*****  " + server.uri() + "  *****");

  requestStatus status = planta.saveWifiCredentials(body);
  response = buildHttpResponse(status);
  server.send(response.code, response.contentType, response.body);
}

// ===== OTA local (POST /otaupdate) =====
// Recibe el .bin por multipart y lo escribe en el slot OTA inactivo con la
// librería Update; al terminar OK, el bootloader arrancará el firmware nuevo.
// Requiere doble slot OTA (ver partitions.csv): sin él, Update.begin() falla.
//
// Seguridad (fail-closed): se exige token de sesión vigente Y que la petición
// entre por la interfaz del AP, igual que el resto del plano de control. La
// decisión se toma en UPLOAD_FILE_START —antes de escribir un solo byte— y se
// recuerda en estas variables para que los trozos siguientes y la respuesta
// final actúen en consecuencia.
static bool     otaAuthorized = false;   // token + AP validados en START
static uint16_t otaHttpError  = 0;        // 0 = sin error de autorización

void handleOtaUpload() {
  HTTPUpload& upload = server.upload();

  if (upload.status == UPLOAD_FILE_START) {
    otaAuthorized = false;
    otaHttpError  = 0;

    // ¿Entró por el AP? Igual que en el reset: la IP local del socket es la
    // interfaz que aceptó la conexión (no la puede falsificar el cliente).
    IPAddress apIp = WiFi.softAPIP();
    bool fromAP = (apIp != IPAddress((uint32_t)0)) && (server.client().localIP() == apIp);

    // Token en el header Authorization: Bearer <token>. Se lee de las cabeceras
    // (no del cuerpo, que es multipart), así que llega ANTES del binario y permite
    // autorizar en START, antes de escribir un solo byte en flash.
    // Requiere que "Authorization" se haya registrado con server.collectHeaders()
    // en setup(); si no, WebServer no lo conserva.
    String auth = server.header("Authorization");
    String token = "";
    if (auth.startsWith("Bearer ")) token = auth.substring(7);
    token.trim();

    if (!planta.isSessionValid(token)) {
      otaHttpError = 401;  // sesión inválida/expirada
      return;              // NO se llama a Update.begin(): no se escribe nada
    }
    if (!fromAP) {
      otaHttpError = 403;  // solo por la interfaz del AP
      return;
    }

    Serial.printf("[OTA] Inicio: %s\n", upload.filename.c_str());
    // UPDATE_SIZE_UNKNOWN: el tamaño real se conoce al terminar; Update usa el
    // slot OTA inactivo y valida al final.
    if (!Update.begin(UPDATE_SIZE_UNKNOWN)) {
      Update.printError(Serial);
      otaHttpError = 500;  // no se pudo iniciar (¿sin doble slot OTA?)
      return;
    }
    otaAuthorized = true;

  } else if (upload.status == UPLOAD_FILE_WRITE) {
    if (!otaAuthorized) return;  // subida no autorizada: se ignoran los datos
    if (Update.write(upload.buf, upload.currentSize) != upload.currentSize) {
      Update.printError(Serial);
      otaHttpError = 500;
      otaAuthorized = false;
      Update.abort();
    }

  } else if (upload.status == UPLOAD_FILE_END) {
    if (!otaAuthorized) return;
    if (!Update.end(true)) {   // true = fija el tamaño final y valida la imagen
      Update.printError(Serial);
      otaHttpError = 500;
      otaAuthorized = false;
    } else {
      Serial.printf("[OTA] Completado: %u bytes\n", upload.totalSize);
    }

  } else if (upload.status == UPLOAD_FILE_ABORTED) {
    Update.abort();
    otaAuthorized = false;
    Serial.println("[OTA] Abortado por el cliente");
  }
}

void handleOtaUpdate() {
  // Respuesta final: corre cuando la subida terminó (o falló en autorización).
  Serial.println("*****  /otaupdate  *****");

  // Pitido SÍNCRONO a propósito en este handler: el camino de éxito reinicia el
  // equipo de inmediato (el reproductor no bloqueante del loop no alcanzaría a
  // sonar), y los de error son excepcionales y breves. Fuera de /otaupdate el
  // buzzer siempre es no bloqueante (buzzerBeep/buzzerUpdate).
  auto beepSync = [](uint16_t onMs, uint8_t times) {
    for (uint8_t i = 0; i < times; i++) {
      digitalWrite(buzzerPin, deviceOn);
      delay(onMs);
      digitalWrite(buzzerPin, deviceOff);
      if (i + 1 < times) delay(150);
    }
  };

  if (otaHttpError == 401) {
    beepSync(150, 2);  // error de autorización
    server.send(401, "application/json",
                "{\"status\":false,\"message\":\"Tu sesión expiró. Inicia sesión y reintenta.\"}");
    return;
  }
  if (otaHttpError == 403) {
    beepSync(150, 2);  // error de autorización
    server.send(403, "application/json",
                "{\"status\":false,\"message\":\"La actualización solo se permite desde la red del equipo (AP).\"}");
    return;
  }
  if (otaHttpError != 0 || !Update.isFinished()) {
    beepSync(150, 2);  // fallo de instalación
    server.send(500, "application/json",
                "{\"status\":false,\"message\":\"No se pudo instalar el firmware. El equipo conserva el anterior.\"}");
    return;
  }

  // Éxito: la imagen quedó escrita y validada en el slot inactivo. Respondemos y
  // reiniciamos; el bootloader arrancará el firmware nuevo.
  server.send(200, "application/json",
              "{\"status\":true,\"message\":\"Firmware instalado. El equipo se reinicia.\"}");
  Serial.println("[OTA] Reiniciando al firmware nuevo…");
  beepSync(600, 1);                      // 1 pitido largo = OTA OK, antes del reboot
  vTaskDelay(pdMS_TO_TICKS(400));        // completa ~1 s de margen tras responder
  ESP.restart();
}

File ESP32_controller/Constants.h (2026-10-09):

#ifndef _CONSTANTS
#define _CONSTANTS

#include <Arduino.h>   // HIGH/LOW: este header define niveles lógicos, así que no
                       // depende del orden de inclusión de quien lo use.

// ===== Polaridad de las salidas ON/OFF (relés y LED blanco) =====
// El nivel que ENCIENDE vive SOLO aquí. Antes estaba repartido como HIGH/LOW
// literales en cinco sitios (constructor, allDevicesOff, turnOnDevices y
// manageDevice), y cambiar de módulos "activos en bajo" a "activos en alto"
// obligaba a cazarlos uno por uno con el riesgo de dejar alguno al revés —que en
// la bomba significa regar cuando debería estar apagada—.
//
// Configuración actual: LÓGICA DIRECTA (el pin en alto enciende).
// Si el hardware fuese de relés activos en bajo, basta intercambiar estas dos
// líneas y TODO el firmware queda coherente.
const uint8_t deviceOn  = HIGH;
const uint8_t deviceOff = LOW;

// Pines ESP32 DEV
/*const byte whiteLedPin = 2; // Cambia según tus conexiones
const byte blueLedPin = 14;
const byte redLedPin = 15;
const byte buzzerPin = 4;
const byte waterPumpPin = 16;
const byte fanPin = 17;*/

// Pines ESP32-C3
const uint8_t whiteLedPin = 0;      // Cambia según tus conexiones
const uint8_t blueLedPin = 1;
const uint8_t redLedPin = 2;
const uint8_t buzzerPin = 3;
const uint8_t fanPin = 7;
const uint8_t waterPumpPin = 10;

// Canales PWM. Solo azul y rojo son PWM; el blanco es salida digital (GPIO 0), así
// que no tiene canal asignado.
const uint8_t blueChannel = 1;      // Canal asignado a pwmPin2
const uint8_t redChannel = 2;       // Canal asignado a pwmPin3

// Configuración PWM
const int pwmFrequency = 1000;      // Frecuencia en Hz
const uint8_t pwmResolution = 8;    // Resolución de 8 bits (0-255)
const uint8_t maxDutyCycle = 255;

const uint8_t zero = 0;

// ===== Sesión de edición =====
// Ventana durante la cual un usuario autenticado puede editar parámetros sin
// volver a introducir credenciales. TTL FIJO: se cuenta desde el login y la
// actividad NO lo renueva, así que la sesión caduca 30 min después de iniciar
// sesión. El token vive solo en RAM, así que un reinicio/corte de luz/reset lo
// invalida solo.
const uint32_t SESSION_TTL_MS = 30UL * 60UL * 1000UL; // 30 min

// ¡OJO CON EL ORDEN! _systemStatus se persiste en NVS con putBytes (por ÍNDICE, no
// por nombre): insertar, quitar o reordenar enumeradores reinterpreta lo ya
// guardado. Renombrar SÍ es seguro; mover, no. Y si cambia la CANTIDAD de campos,
// el blob guardado deja de medir lo mismo y Preferences::getBytes no copia nada
// (devuelve 0 si lo guardado es más grande que el buffer), así que la config se
// leería en ceros: al cambiar campos, borra la flash antes de cargar el firmware.
//
// Correspondencia con las claves JSON del portal:
//   ledAzul   -> blueDutyCycle    (PWM, 0-100 %)
//   ledRojo   -> redDutyCycle     (PWM, 0-100 %)
//   ledBlanco -> whiteLedOn       (ON/OFF, 0/1: salida digital, no PWM)
enum SystemStatus : uint8_t {
    hasRegisteredUser = 1,
    hasWifiCredentials,
    systemEnable,
    photoperiodOn,            // hora de prendido de las luces (0-23)
    photoperiodOff,           // hora de apagado de las luces (0-23)
    blueDutyCycle,
    redDutyCycle,
    whiteLedOn,               // LED blanco: salida DIGITAL (GPIO 0), no PWM. Se
                              // guarda normalizado a 0/1; cualquier valor > 0 enciende.
    irrigationFrequency,
    irrigationDuration,
    ventilationFrequency,
    ventilationDuration,
    systemStatusCount         // centinela: NO es un campo, marca el tamaño necesario
};

enum currentTime : uint8_t {
    second = 1,
    minute,
    hour,
    dayOfWeek,
    day,
    month,
    year,
    currentTimeCount          // centinela: NO es un campo, marca el tamaño necesario
};

// ===== Versión del firmware =====
// Se reporta en GET /getparams (clave "firmwareVersion") y la vista OTA del
// portal la muestra como "versión actual". Es una constante de COMPILACIÓN, no
// un valor en NVS, a propósito: la versión describe al binario que se está
// ejecutando. Si se guardara en NVS, tras un OTA el binario nuevo seguiría
// reportando la versión vieja hasta que alguien reescribiera ese registro.
// Así, cada binario dice exactamente lo que es.
// -> SUBIR ESTE VALOR en cada release que se vaya a distribuir por OTA.
// (const char* const: puntero const, para que el header pueda incluirse en
//  varias unidades de compilación sin colisión de símbolos en el enlazado.)
const char* const firmwareVersion = "1.0.0";
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

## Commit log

2024-03-01 schematics and board added
    [ESP32_Board.kicad_pcb, ESP32_Board.kicad_sch]
2024-03-03 schematics and board deleted
    [ESP32_Board.kicad_pcb, ESP32_Board.kicad_sch]
2025-04-15 fix in registerUser path
    [Plant.cpp]
2025-06-09 database connector added
2025-06-20 OTA dowload added to ESP32 files
2025-06-21 fixed OTA update issues
    [Constants.h, Plant.cpp]
2025-06-25 OTA updates issues fixed
    [Plant.cpp]
2025-06-30 OTA logic is working, to avoid reading OS files in this route
    [Plant.cpp]
2025-09-29 arduino PWM functions updated
2026-04-07 formulario de registro de usuario actualizado
2026-04-08 formulario de registro de usuario actualizado 07-04-26
2026-04-14 formulario de nuevos parametros actualizado 13-04-26
2026-05-01 Cambios en el formulario
2026-06-12 samodifica el alrgo del password para aceptar el comando reset
2026-06-15 Se acualiza la logica del controlador ESP32 C3
2026-06-17 Se añade logica para el rtc
2026-06-19 Se unifican nombres
    [rutas_y_parametros.txt]
2026-07-10 Se añaden archivos utils para funciones que no pertenecen planta
2026-07-15 Refactor a la clase planta
2026-07-26 actualización de form
2026-08-11 cambio de logica para activar gpios
2026-09-02 se sube un archivo HTML con la lógica de wifiscan y envio de token
2026-09-04 se actualizan archivos de firmware
2026-09-10 Se modifica el html v2
2026-09-23 actualización de backend docs
2026-09-23 Se modifica el formulario del dispositivo y la v2
2026-09-23 Cambios en el firmware
2026-09-23 Actualización de docs
2026-09-23 se actualizan logs de firmware
2026-09-27 actualización de readme
2026-09-27 Actialización de Formualrio v1 y v2
2026-09-27 Se gregó local OTA update
    [partitions.csv]
2026-09-27 se añadieron skills para los agentes
2026-09-29 Actualización de form v2
2026-09-29 Actualización de form en firmware
2026-09-29 Actualización de notas
2026-09-29 esquema de particiones esp32 c3
2026-10-01 Actualización de formularios
2026-10-01 Actualización de esquema de particiones de ESP32
    [partitions.csv]
2026-10-01 Se corrige la ruta newparams en el formulario, no hace trim a campo de firmware
2026-10-07 Se actualizan archivos para generar el zip que expone el firmware
2026-10-09 Etapa de potencia, buzzer no bloqueante y documentación de hardware
    [Constants.h, ESP32_controller.ino, Plant.cpp]
2026-10-19 docs: aclarar las dos bases de firmware (Arduino vs ESP-IDF)
    Explica que ESP32_controller/ es el firmware estable Arduino (main) y que la
    migracion a ESP-IDF puro vive en la rama esp-idf-migration (carpeta firmware/).
    Portal, backend, hardware y docs son comunes. Narrativa identica a la de la rama
    de migracion; el arbol de main no lista firmware/ porque no existe en esta rama.
2026-10-23 docs(hardware): etapa de potencia (opto PC817 + MOSFET + snubber) y pines I2C
2026-10-26 docs(hardware): bobina flexible 5/12/24V, LED al lado de control, jumper de tierras
2026-10-27 docs(hardware): placeholders para capturas de esquemático (salida digital, PWM, buzzer)
2026-10-27 firmware(arduino): serial muestra día-en-semana como el dashboard
2026-10-27 docs(hardware): corregir esquema del buzzer (circuito válido) y unificar MOSFET a AO3400A
2026-11-02 notas: pruebas pendientes de paridad IDF y decisiones abiertas (DNS, 405, subred)
2026-11-04 docs/notas: DNS captivo ligado al AP y '/' multimétodo en IDF (diferencia con Arduino)
2026-11-04 portal: promover el rediseño hub-and-spoke a versión activa
    - HTML/mainForm.html ahora es el portal hub-and-spoke (antes HTML/portal-dev/)
    - portal lineal anterior archivado en HTML/deprecated/mainForm.html
    - HTML/dev/ reservado para la próxima ronda (paletas-guardadas.css)
    - generadores movidos a HTML/scripts/ con rutas ancladas a la raíz del repo
    - regenerado mainForm.h (14757 B gzip) y mainForm.preview.html
    - docs y notas actualizadas al modelo de una pista activa
2026-11-05 portal: dar vida a los temas claros sin tocar los colores de las paletas
    Fondo con degradado sutil, sombra de tarjeta con cuerpo y filo superior de
    color, todo derivado de las variables de la paleta activa con color-mix (sin
    colores literales nuevos). Limitado a los temas claros; verde-oscuro intacto.
    Regenerados mainForm.h y mainForm.preview.html.
2026-11-05 portal: tema invernadero activo, botones parejos y Salir en rojo del tema
    - paleta activa del portal: invernadero (antes tierra); tierra queda en paletas-guardadas.css
    - efectos de vida (banda de titulo con color, fondo con focos, sombra con cuerpo) revisados
    - .actions button a flex 1 1 0: botones de igual ancho en welcome y OTA
    - #btnExit (dashboard) usa el rojo del tema (secondary/secondary-2) con el mismo
    tratamiento que los otros nav-item; fondo derivado con color-mix (sin colores nuevos)
    - 3 paletas oscuras candidatas (carbon, medianoche, bosque-noche) guardadas en dev/
    - regenerados mainForm.h y mainForm.preview.html
2026-11-05 docs: separar presentar / demostrar ingeniería / estado
    - README reordenado para ingeniería: qué controla y cómo, configuración (tabla),
    hardware, portal, arquitectura, gancho de ingeniería; sin tabla de trade-offs
    ni roadmap de casillas embebidos
    - ARCHITECTURE: nueva sección 'Decisiones de ingeniería (resumen)' que indexa y
    enlaza las decisiones ya documentadas; + flujo de trabajo del portal (movido del README)
    - ROADMAP: reencuadrado como 'Estado y roadmap'; leyenda de nivel de evidencia y
    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
2026-11-06 renombrar LED blanco -> Lámpara (control principal ON/OFF)
    La salida digital GPIO 0 pasa a llamarse Lámpara: control principal de
    iluminación ON/OFF que admite lámparas de cultivo comerciales con control
    ON/OFF; los 2 canales PWM (azul/rojo) quedan como opción avanzada.
    - contrato JSON: ledBlanco -> lampara; error INVALID_WHITE_LED_VALUE -> INVALID_LAMP_VALUE
    - firmware Arduino: whiteLedPin/whiteLedOn -> lampPin/lampOn; mensaje y log serie
    - portal: etiquetas, ids y mock de preview; regenerados mainForm.h y preview
    - docs: README (sección Iluminación reescrita, tabla de config), API, ARCHITECTURE,
    HARDWARE, BACKEND/API-backend (texto); README.en alineado (lógica directa)
    - backend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
2026-11-06 docs: índice del README con encabezados en mayúsculas y ancla #iluminación; notas de prueba del renombrado
    El cambio del índice (mayúsculas) viene de la edición hecha en esp-idf-migration
    (b57adfd); se corrige el ancla al encabezado actual (#iluminación).
2026-11-06 docs(readme): iluminación en dos niveles de control (lámpara ON/OFF y espectros azul/rojo opcionales)
2026-11-06 docs(readme): riego presentado por su flexibilidad (frecuencia y duración independientes)
    Corrige además la tabla de configuración: el portal ofrece frecuencias de cada hora
    hasta semanal (168 h), no 'cada 2 semanas' (336 h existe solo en constantes del IDF).
2026-11-06 docs(readme): indicar GPIO 10 en la sección de riego
2026-11-06 docs(readme): rango de duración (0–59 min por ciclo) en riego y ventilación
2026-11-06 docs(hardware): corregir relación azul:rojo (5:1), nota de strapping GPIO 2/8/9, bloque sin cerrar; PWM opcional
    - relación 'azul:rojo' estaba invertida (1:5) respecto a 100 W / 20 W
    - dimensionado de LED reencuadrado como referencia opcional a criterio del usuario
    - nota de strapping: GPIO 2, 8 y 9 (SDA/SCL del DS3231 caen en 8/9); datos de GPIO 8/9 según Espressif
    - eliminado un marcador de bloque de código sobrante que invertía el render desde la sección del buzzer
2026-11-06 notas: pendientes de hardware/documentación (PWM LED, strapping, esquemáticos) y prueba de strapping en placa
    - PWM de LED se deja como está; se guarda la evaluación del buffer 74AHCT 3.3->5 V
    con sus cuidados y lo no verificado
    - decisiones abiertas: tipo de arreglo LED, MOSFET del canal azul, esquemáticos reales,
    conexión de LED de usuario, bobina de contactor, criterio de la fuente
    - documentación: README.en.md, sección Ventilación, tope de 59 min
2026-11-08 cambio de logica para encender los gpio
2026-11-09 docs: documentar la polaridad activa en bajo (firmware Arduino 1.0.1)
    El commit be14ed7 invirtió deviceOn/deviceOff (LOW enciende). Se actualizan los
    textos que seguían diciendo 'lógica directa' (README es/en, API, ARCHITECTURE,
    HARDWARE y comentarios de Constants.h; sin cambios de código).
    HARDWARE.md: aviso de que los esquemáticos de salida digital y de buzzer siguen
    siendo activos en alto (con este firmware, 'apagado' energizaría la carga y el
    buzzer sonaría en reposo). notas.txt: prueba en placa y decisiones abiertas
    (buzzer, estado de arranque, paridad con el IDF).
2026-11-09 docs(hardware): salidas ON/OFF activas en bajo con opto en sumidero y buzzer con inversor
    - salida digital (lámpara, bomba, ventilador): opto PC817 en sumidero
    (+3.3 V -> ánodo, cátodo -> R -> GPIO); verificado en la placa por el usuario.
    Sin pull-down: en alta impedancia el opto no conduce.
    - buzzer: también activo en bajo; circuito de dos AO3400A (inversor + interruptor)
    documentado como PROPUESTA sin probar.
    - nueva sección 'Polaridad de las salidas ON/OFF' (sustituye al aviso provisional).
    - README es/en (fila del buzzer), comentario de Constants.h y notas.txt al día.
2026-11-09 docs(hardware): corregir el lado de potencia de las salidas digitales y definir el buzzer TMB12A05
    - lado de potencia: el fototransistor pasa a seguidor de emisor (colector a +Vb,
    emisor -> 10k -> gate, 100k a GND_potencia) con Zener de 10 V en el gate.
    El diagrama anterior (colector al gate con pull-up de 10k, emisor a tierra)
    invertía la señal, dejaba la carga encendida en el arranque y a 24 V superaba
    el Vgs máximo del AO3400A (±12 V).
    - estado real: lado de control verificado en la placa (LED indicador en sumidero);
    lado de potencia y buzzer son diseño aún sin montar.
    - buzzer: TMB12A05 (5 V, <=30 mA, 2300 Hz) con dos AO3400A, activo en bajo.
    - restaurado el encabezado '#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
